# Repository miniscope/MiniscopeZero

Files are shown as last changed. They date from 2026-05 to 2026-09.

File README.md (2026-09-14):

# Miniscope Zero

Repository for **Miniscope Zero: a fully wireless, single-cell-resolution miniature microscope for imaging neural dynamics in freely behaving animals**.

Miniscope Zero is a miniature one-photon microscope that operates without tethers: power is delivered via quasistatic cavity resonance (QSCR) wireless power transfer, and imaging data is streamed over a high-bandwidth optical link. This repository hosts the project-specific hardware designs — the miniscope, the optical data acquisition hardware, and the QSCR arena — and points to the related software and hardware repositories.

- Preprint: [bioRxiv](https://doi.org/10.64898/2026.09.05.745822) (doi:10.64898/2026.09.05.745822)
- Wiki: https://miniscope.org/wiki/Miniscope_Zero
- License: [CERN-OHL-S v2](LICENSE) — bundled code retains its original license where noted: the vendored [Miniscope-SAMD-Framework](https://github.com/miniscope/Miniscope-SAMD-Framework) snapshot (`MS_module`) is AGPL-3.0, and Microchip ASF/Atmel START driver code keeps Microchip's license

Co-led by Takuya Sasatani ([@t-sasatani](https://github.com/t-sasatani)) and Marcel Brosch ([@MarcelMB](https://github.com/MarcelMB)).

## Demonstration video
https://github.com/user-attachments/assets/aa9ec822-df9f-4f50-9b2d-21a6ab23955f

## Repository contents

```
MiniscopeZero/                      Wireless miniscope
├── Firmware/                       SAMD51 firmware (Microchip Studio project)
├── Optics/                         Optical system
│   ├── optics_bom.csv              Bill of materials for the optical path
│   ├── mechanical/                 Dimensioned drawing of the optical assembly
│   ├── zemax/                      Zemax OpticStudio sequential design files
│   ├── housing/                    3D-printed housing: STEP, Fusion archive, per-body STLs
│   └── baseplate/                  CNC-machined baseplate, 3D-printed dust cap,
│                                   and set-screw hardware list
└── PCB/                            Electronics
    ├── WLMS-v0_2_1-motherboard/    Main board: PYTHON480 image sensor, MCU, PMU,
    │                               excitation LED, IR receiver
    ├── WLMS-v0_2_9_daughterboard/  Power/uplink board: rectifier, pre-regulator,
    │                               TX LED for the optical data link
    └── WPT_receiver/               Rectangular wireless power receiver coils

OpticalDAQ/                         Receiver-side data acquisition hardware
├── PCB/
│   ├── optical_daq_v0_4/           Photoreceiver front end: VGA board and digitizer board
│   ├── optical_downlink_v0_2/      USB board for the IR downlink
│   └── FPGA_breakout/              Breakout board for the Opal Kelly XEM7310 FPGA module
└── Housing/                        CNC aluminum shield box

QSCR/                               Quasistatic cavity resonance power-transfer arena
├── COMSOL/                         Electromagnetic simulation models of the arena
├── Fusion360/                      QSCR behavioral arena design files
└── PCB/c_mount/                    Capacitor mount PCB

guides/                             Build and operation guides
├── optics_assembly.md              Assembling the miniscope printed parts and optics
├── qscr_operation.md               QSCR cavity operation, tuning, and assembly
└── img/                            Figures for the guides
```

## Related repositories (developed by authors)

- [mio (Miniscope-I/O)](https://github.com/miniscope/mio) — data acquisition, synchronization, and preprocessing
- [CaMAP](https://github.com/miniscope/CaMAP) — calcium imaging mapping and analysis pipeline
- [miniscope_preproc](https://github.com/miniscope/miniscope_preproc) — preprocessing for Miniscope Zero calcium imaging videos
- [wpt-devkit](https://github.com/SasataniLab/wpt-devkit) — wireless power transmitter
- [FuzzyTrack](https://github.com/miniscope/FuzzyTrack) — diffused LED position tracking
- [Miniscope-SAMD-Framework](https://github.com/miniscope/Miniscope-SAMD-Framework) — firmware framework template; `Firmware/.../MS_module` is a minimal vendored snapshot of [v0.3.1](https://github.com/miniscope/Miniscope-SAMD-Framework/tree/v0.3.1)

## Hardware modules

Off-the-shelf or reference modules used in the system:

- [Hamamatsu C15522-3010SA](https://www.hamamatsu.com/us/en/product/optical-sensors/mppc/mppc-module/C15522-3010SA.html) — SiPM (MPPC) module, receiver for the optical data link
- [EPC9065](https://epc-co.com/epc/products/evaluation-boards/epc9065) — high-frequency ZVS class-D power amplifier, drives the QSCR cavity
- [Opal Kelly XEM7310](https://www.opalkelly.com/products/fpga-integration/XEM7310/) — Artix-7 FPGA board for data acquisition

## Batteries

- [Powerstream GM041215](https://www.powerstream.com/ultra-light.htm) — Low weight miniature lithium ion battery, 45mAH, 3.7V, 4x12x15 mm, 1 g
- [Powerstream GM300910](https://www.powerstream.com/ultra-light.htm) — Low weight miniature lithium ion battery, 11mAH, 3.7V, 3x9x10 mm, 0.33 g

## Contributing

This repository primarily archives the design files accompanying the paper, so
pull requests are unlikely to be merged. Questions and issue reports are
welcome via the issue tracker, though we cannot guarantee a response.

## Wireless system video
https://github.com/user-attachments/assets/bc67a5da-3641-4dcf-a8c2-b1db79f1c406

## Citing

If you use this work, please cite the [preprint](https://doi.org/10.64898/2026.09.05.745822) — BibTeX in [CITATION.bib](CITATION.bib), or use GitHub's "Cite this repository" button.

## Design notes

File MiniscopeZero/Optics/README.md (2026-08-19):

# Optics

Optical system of the Miniscope Zero head-mounted assembly: bill of materials,
mechanical drawing, optical design files, and housing/baseplate CAD.

## Contents

```
Optics/
├── optics_bom.csv    Bill of materials for the optical path
├── mechanical/       Dimensioned drawing of the optical assembly (Fusion 360 export)
├── zemax/            Ansys Zemax OpticStudio sequential-mode design files
├── housing/          3D-printed optical housing CAD
└── baseplate/        3D-printed baseplate CAD and hardware list
```

The housing holds the optical stack; the baseplate is cemented to the skull and
receives it. A set-screw mechanism sets the focal plane relative to the implanted
GRIN lens during baseplating, then locks it for subsequent recordings.

## Assembly

[`guides/optics_assembly.md`](../../guides/optics_assembly.md) is the build guide for the head-mounted assembly:
which optic goes into which printed part and in which orientation, edge
blackening and adhesive practice, the order the four printed parts are joined
in, and a dark-field leak test to run before the scope goes on an animal.

## Bill of materials

`optics_bom.csv` lists every element in the optical path. GitHub renders it as a
table in the web UI. The `ref` column keys each part to the mechanical drawing:

| ref | Element |
| --- | --- |
| `LED` | Excitation LED |
| `F_ex` | Excitation filter |
| `DM` | Dichroic beamsplitter |
| `L1`, `L2` | Objective (L2 is closest to the sample) |
| `L3` | Tube lens |
| `M1` | Fold mirror |
| `F_em` | Emission filter |
| `IS` | Image sensor |

Light path: `LED → F_ex → DM (transmitted) → L1 → L2 → sample`, then
`sample → L2 → L1 → DM (reflected 90°) → L3 → M1 (folded) → F_em → IS`.

Folding the path twice distributes the elements laterally rather than
vertically, keeping the assembly height low.

The `notes` column records where a part is **modified from stock** — the filters,
dichroic, and mirror are all diced down from larger catalog parts. Ordering the
stock part number alone will not give you a part that fits the housing.

Links in the `link` column point to the vendor part page, or to a vendor search
for the stock number where no stable product URL exists.

## Mechanical drawing

`mechanical/drawing_Miniscope_Wireless_emission_v_0_2_10.pdf` — dimensioned
layout of the optical stack, exported from Fusion 360 (design v0.2.10), with
element spacings in mm.

## Housing

`housing/` holds the 3D-printed optical housing (design v0.2.10):

- `Wireless_Miniscope_v_0_2_10.step` — all four bodies as exact solids. Use this
  to modify the design in any CAD package.
- `Wireless_Miniscope_v_0_2_10.f3d` — Fusion 360 archive with the design history.
- One STL per body, for printing:

| File | Body | Size (mm) |
| --- | --- | --- |
| `base_unit.stl` | Main chassis, tube-lens bore | 11.3 x 13.0 x 9.0 |
| `objective_unit.stl` | Objective lens holder | 7.9 x 2.1 x 7.9 |
| `excitation_unit.stl` | Excitation LED and filter arm | 7.6 x 7.6 x 9.0 |
| `focus_slider_unit.stl` | Set-screw focus slider | 8.4 x 10.0 x 8.0 |

The four parts print separately. Each STL is a single watertight, manifold shell
at the origin, so it can be oriented independently in the slicer.

Printed on a Formlabs Form 4 in Black Resin V5 at 25 um layer thickness.

## Baseplate and dust cap

`baseplate/` holds the skull-mounted baseplate and its dust cap. The two are
made differently:

| Part | Process | File to use |
| --- | --- | --- |
| Baseplate | CNC machined (Protolabs) | `baseplate.step` |
| Dust cap | 3D printed | `dust_cap.stl` |

The dust cap prints on the same settings as the housing: Formlabs Form 4, Black
Resin V5, 25 um layer thickness.

Baseplate machining specification (as ordered from Protolabs):

| | |
| --- | --- |
| Material | Aluminium 7075-T651 |
| Process | Mill |
| Dimensions | 14.59 x 5.99 x 14.89 mm |
| Tolerance | +/- 0.005 in (0.13 mm) |
| Edges | Broken; tool marks visible |
| Internal corners | Sharp, at minimum tool radius |
| Threading | 1 feature, UNF #2-64 |

The threaded bore is highlighted in green below. It takes the set screw that
locks the optical stack in the baseplate once the focal plane is set.

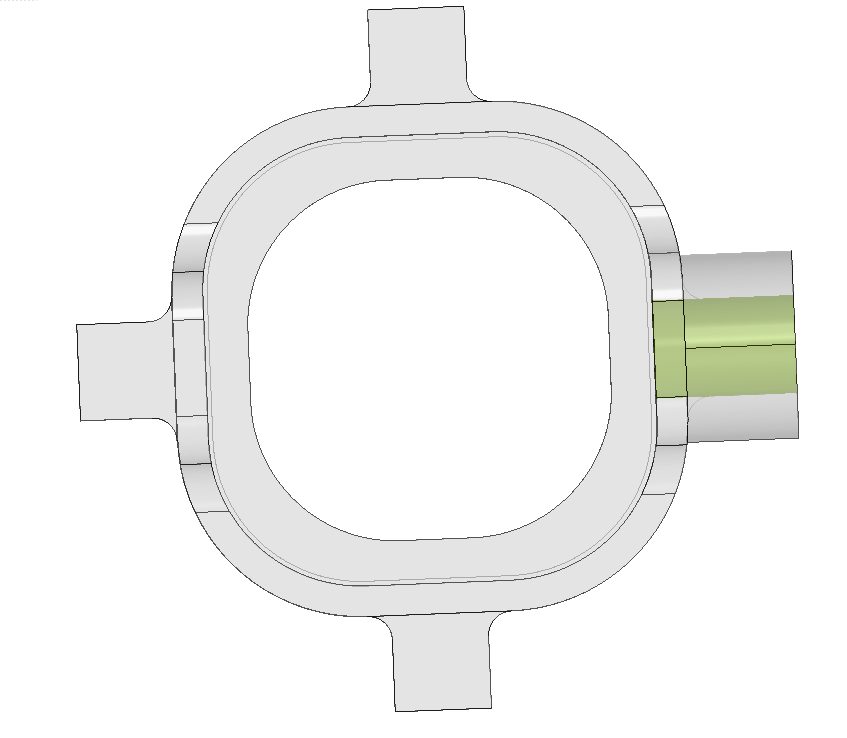
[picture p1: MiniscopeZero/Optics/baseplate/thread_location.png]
Baseplate seen from above, with the UNF #2-64 threaded bore highlighted in green


`baseplate.step` is the exact solid sent for machining; `baseplate.stl` is the
tessellated equivalent, for viewing and fit checks. `baseplate_and_dustcap.f3z`
is the Fusion 360 assembly archive for both parts.

`baseplate/baseplate_components.csv` lists the hardware that goes with it: the
McMaster-Carr `92311A317` set screw (18-8 stainless, cup tip, 2-64 UNF x 1/8 in,
0.035 in / 0.9 mm hex drive) and the precision hex driver used to turn it.

## Optical design

`zemax/` contains the sequential-mode OpticStudio models:

- `Miniscope_Wireless_emission_v_0_2_6_mirror_as_prism_2ndaspheric_14572.zmx`
  — emission path (the fold mirror is modelled as a prism).
- `Miniscope_Wireless_excitation_v_0_2_2.zmx` — excitation path.
- `emission_prescription_data.txt` — prescription dump of the emission model
  (surface data, NA, working F/#, track length), readable without OpticStudio.

`.ZDA` files are the matching OpticStudio session/analysis files.

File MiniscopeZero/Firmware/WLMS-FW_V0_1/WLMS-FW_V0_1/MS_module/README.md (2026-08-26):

# Miniscope-SAMD-Framework

Firmware framework for wireless miniature microscopes (miniscopes) based on Microchip SAM D51 microcontrollers. The framework reads out a CMOS image sensor (ON Semiconductor PYTHON 480 or AMS NanEye) through the parallel capture controller (PCC), buffers image data in MCU RAM, and streams it via DMA to a serial data link (SPI/USART) or an SD card. It also controls miniscope peripherals such as the electrowetting lens (EWL), excitation LED, battery and wireless-power voltage monitoring, an IR receiver for remote control, and status LEDs.

The framework is designed to be used as a git submodule inside a Microchip Studio (Atmel START) project. Pre-build scripts link the framework sources into the generated project so that Atmel START files are never edited directly.

## Repository structure

- `src/`: application sources
- `include/`: headers, including the build configuration (`MS_config.h`)
- `ASF_custom/`: customized Atmel Software Framework (ASF) drivers, stored with `.csrc`/`.hsrc` extensions and installed by the pre-build script
- `script/`: PowerShell scripts that install/uninstall the framework sources into the parent Atmel START project
- `atstart/`: Atmel START configuration archives (`.atzip`) for supported hardware
- `main.csrc`: application entry point, installed as the parent project's `main.c`
- `Doxyfile`, `html/`: Doxygen documentation; open `html/index.html` in a browser after cloning

## Requirements

- Microchip Studio with an Atmel START project targeting a SAM D51 device
- PowerShell (invoked by the pre-build event)

## Setup

1. Create an Atmel START project configured with the drivers and pins listed under [Peripheral requirements](#peripheral-requirements-atmel-start-config). The archives in `atstart/` can be used as a starting point.
2. From the directory containing the project's `main.c`, add this repository as a submodule:
   ```bash
   git submodule add https://github.com/Aharoni-Lab/Miniscope-SAMD-Framework ./MS_module
   ```
3. In the Microchip Studio Solution Explorer, click "Show All Files", right-click `MS_module`, and select "Include in Project".
4. Add the following to the include paths (Project -> Properties -> Toolchain -> ARM/GNU C Compiler -> Directories, configuration: All configurations):
   ```
   ../MS_module/include
   ```
5. Add the following pre-build event (configuration: All configurations):
   ```
   powershell.exe -ExecutionPolicy Bypass -NoProfile -NonInteractive -File "..\MS_module\script\MS_prebuild.ps1"
   ```

The pre-build script replaces the generated `main.c` and selected ASF drivers with the versions in this repository (`main.csrc`, `ASF_custom/`) using hard links. Before re-running Atmel START code generation, run `script/MS_pre_reconfig.ps1` to restore the original files.

Do not modify Atmel START generated driver files directly. To customize an ASF driver, add the modified file to `ASF_custom/` (with a `.csrc`/`.hsrc` extension) and register its path in `$cfilepatharray`/`$headerpatharray` in `MS_prebuild.ps1` and `MS_pre_reconfig.ps1`.

## Configuration

All build configuration is done with compile-time flags in `include/MS_config.h`.

### Mode flags

Select exactly one hardware mode (`*_MODE` or `*_TESTMODE`), which determines the data path and the set of peripherals compiled in:

```c
// ------ HARDWARE MODE ------------------------
//#define V4WF_MODE
#define WLMS_SPI_MODE
//#define BERT_MODE
//#define GS_MODE
//#define WLMS_USART_MODE
//#define WLMS_SD_MODE
//#define DMA_TO_SPI_TESTMODE
//#define DMA_TO_SPI_METRO_TESTMODE
```

For example, `WLMS_SPI_MODE` streams PYTHON 480 image data over SPI, `WLMS_SD_MODE` records to an SD card, and `BERT_MODE` streams a PRBS test pattern for bit-error-rate testing of the data link.

### Peripheral flags

Each mode defines the peripherals to enable (`*_ENABLE` / `*_DISABLE`) together with mode-specific parameters (buffer sizes, frame rate, sensor ROI, device ID, etc.):

```c
#ifdef WLMS_SPI_MODE
#define PYTHON480_ENABLE
#define EWL_ENABLE
#define DMA_TO_SPI_ENABLE
#define EXLED_PWM_ENABLE
#define BATTERY_ENABLE
// ...
#endif
```

### Conditional compilation

Peripheral code should be guarded by the peripheral's `_ENABLE` flag (not by mode flags):

```c
#ifdef PYTHON480_ENABLE
gpio_set_pin_level(EN_3V3, true); // Enable the 3.3V regulator
I2C_BB_init();
#endif
```

### SERCOM for data output

The SERCOM used for serial data output is configured in Atmel START. On the firmware side, select the corresponding `SPI_SERCOMx_ENABLE` or `USART_SERCOMx_ENABLE` flag in the mode definition; the DMA destination register is resolved from this flag (see `src/MS_global_variable.c`).

## Peripheral requirements (Atmel START config)

### PYTHON480_ENABLE

Drivers:

```
TIMER_0
CAMERA_0
EXTERNAL_IRQ_0
```

Pins:

```
SPI_BB_SCK
SPI_BB_MOSI
SPI_BB_MISO
SPI_BB_NSS
PCC_D0,...,PCC_D7
PCC_CLK
PCC_HV
PCC_FV
FrameValid
EN_3V3
RESET_CMOS
MONITOR0
GCLK1_OUT
```

### BATTERY_ENABLE

```
BATT_VOLT
```

### WPT_ADC_ENABLE

```
WPT_VOLT
```

### EWL_ENABLE

```
I2C_BB_SCL
I2C_BB_SDA
```

### IR_TRIGGER_ENABLE / IR_UART_ENABLE

```
IR_RX
```

### EXLED_PWM_ENABLE

```
LED_PWM
ENT_LED
```

## Documentation

API documentation is generated with Doxygen and committed under `html/`; open `html/index.html` in a browser. To regenerate, run `doxygen Doxyfile` in the repository root.

## License

This project is licensed under the GNU Affero General Public License v3.0; see [LICENSE](LICENSE). The modified ASF driver files in `ASF_custom/` are derived from the Atmel Software Framework and retain their original Microchip/Atmel license headers.

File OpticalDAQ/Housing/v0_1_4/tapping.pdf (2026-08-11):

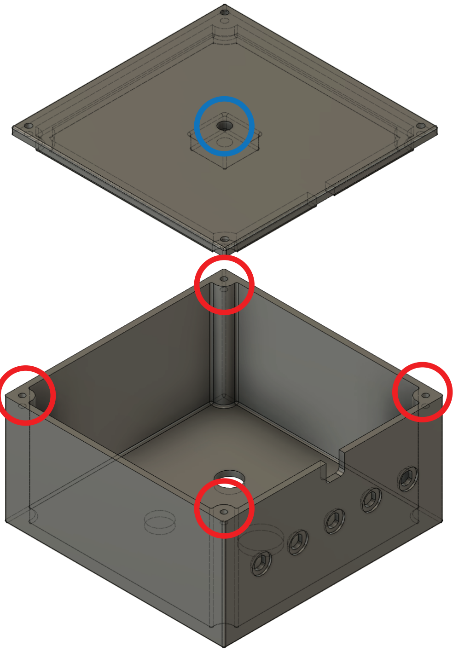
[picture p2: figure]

Red circled holes: M, mm depth thread

Blue circled hole:
UNC/- (JIS B compliant) with a depth of mm

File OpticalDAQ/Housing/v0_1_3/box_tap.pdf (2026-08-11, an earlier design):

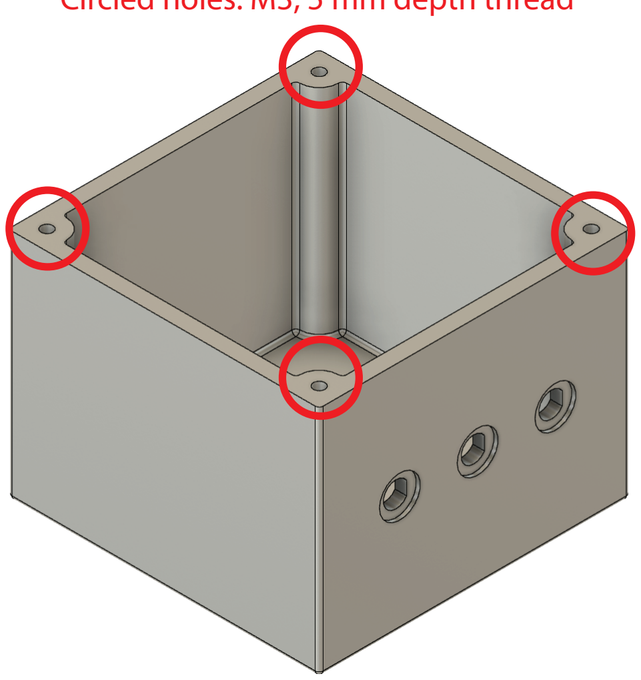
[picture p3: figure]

Circled holes: M3, 5 mm depth thread

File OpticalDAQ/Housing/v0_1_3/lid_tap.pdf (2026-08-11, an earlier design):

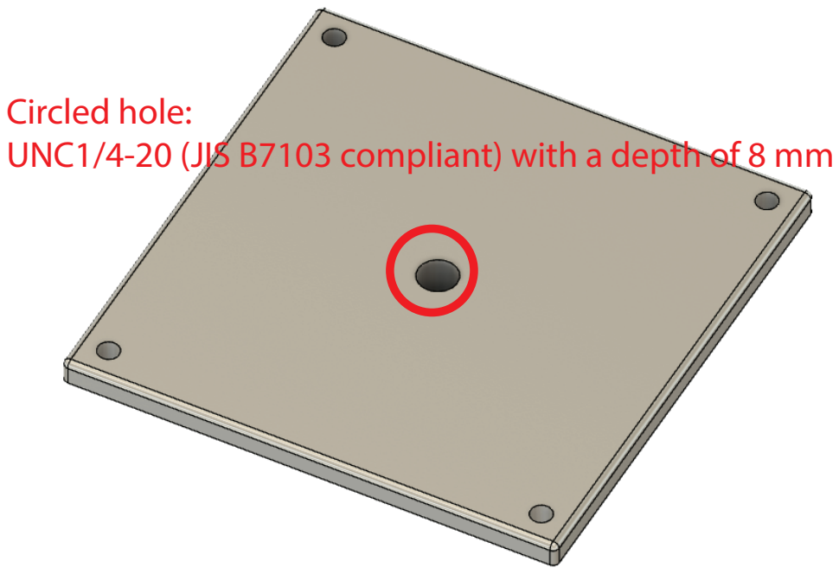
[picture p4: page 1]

Circled hole:
UNC1/4-20 (JIS B7103 compliant) with a depth of 8 mm

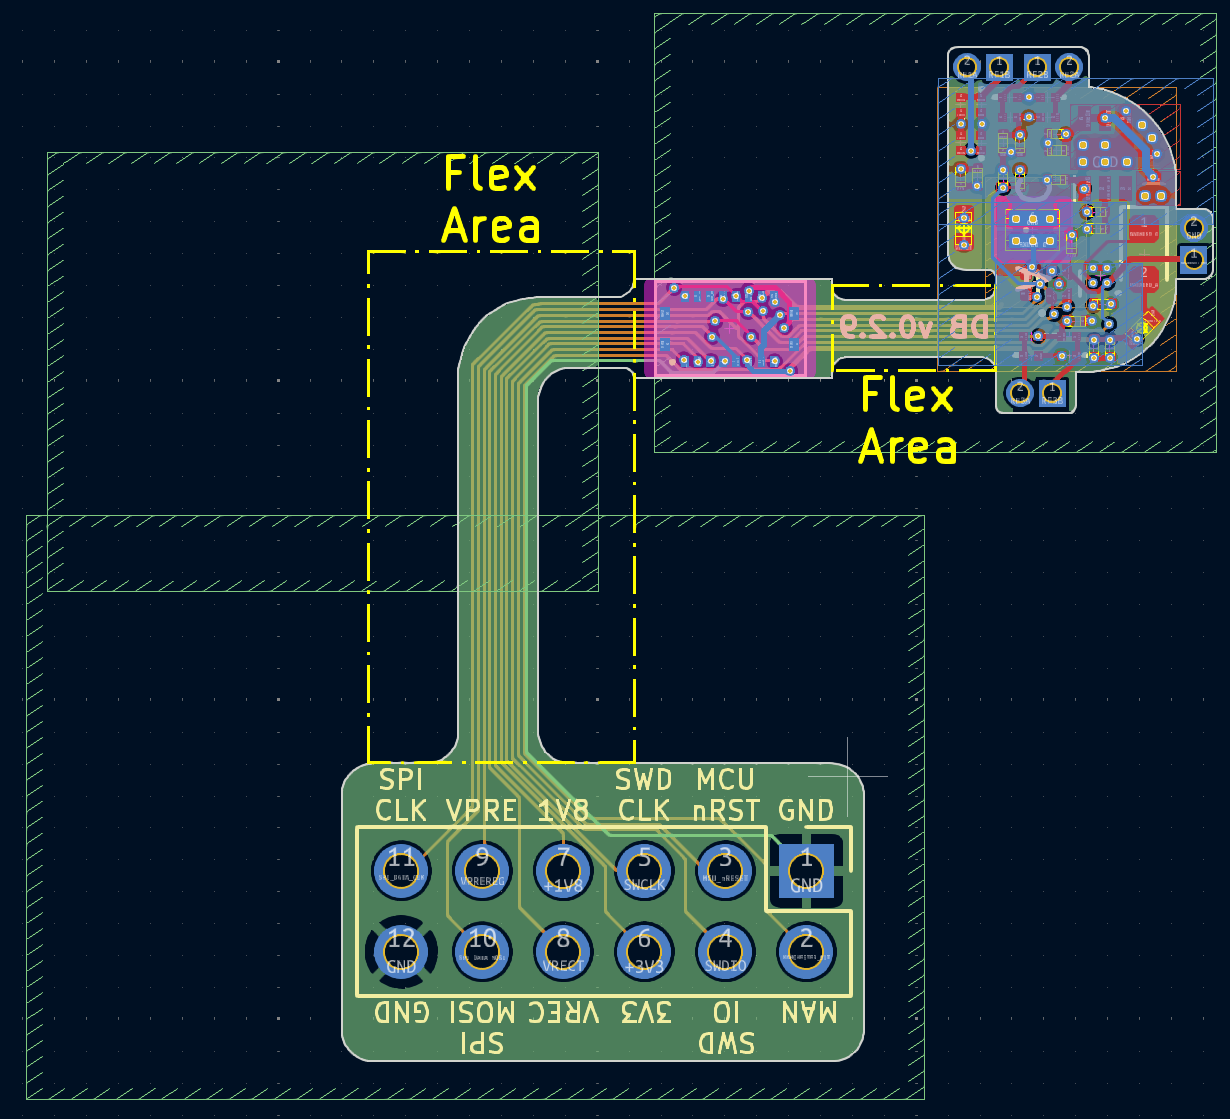
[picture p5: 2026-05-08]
MiniscopeZero/PCB/WLMS-v0_2_9_daughterboard/Assembly/rigid-flex-overview.png

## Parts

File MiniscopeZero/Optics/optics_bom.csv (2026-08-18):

ref | category | component | vendor | part_number | qty | specs | notes | link
LED | excitation | Excitation LED | Lumileds | LXZ1-PB01 | 1 | LUXEON Z blue; 470 nm dominant (460-480 nm); 1.3 x 1.7 mm emitter; ~3 V |  | https://lumileds.com/products/color-leds/luxeon-z-colors/
F_ex | excitation | Excitation filter | Chroma | ET470/40x | 1 | Bandpass 450-490 nm | Diced to 2 x 2 x 0.5 mm | https://www.chroma.com/products/parts/et470-40x
DM | shared | Dichroic beamsplitter | Chroma | T500spxr | 1 | Shortpass, ~500 nm edge; transmits 470 nm excitation, reflects 525 nm emission | Diced to 5 x 7 x 1 mm | https://www.chroma.com/products/parts/t500spxr
L1 | objective | Molded asphere | Edmund Optics | 15-273 | 1 | Polycarbonate; 8.0 mm dia; EFL 5.9 mm; uncoated | Objective, dichroic side | https://www.edmundoptics.com/search/?criteria=15-273
L2 | objective | Plano-convex lens | Edmund Optics | 45-226 | 1 | N-BAF10; 4.0 mm dia; EFL 8.0 mm; MgF2 AR 400-700 nm | Objective, closest to sample | https://www.edmundoptics.com/search/?criteria=45-226
L3 | emission | Molded asphere (tube lens) | Edmund Optics | 14-572 | 1 | Polycarbonate; 8.0 mm dia; EFL 6.9 mm; uncoated |  | https://www.edmundoptics.com/search/?criteria=14-572
M1 | emission | Fold mirror | Thorlabs | PFR10-P01 | 1 | UV fused silica; 25 x 36 x 1 mm stock; protected silver (P01); Ravg > 97% 450 nm - 2 um | Diced to 5 x 7 x 1 mm | https://www.thorlabs.com/thorproduct.cfm?partnumber=PFR10-P01
F_em | emission | Emission filter | Chroma | ET525/50m | 1 | Bandpass 500-550 nm | Diced to 5 x 5 x 1 mm | https://www.chroma.com/products/parts/et525-50m
IS | emission | Image sensor | onsemi | NOIP1SN0480A-STI | 1 | PYTHON 480 monochrome CMOS; 808 x 608 px; 4.8 um pixel; global shutter |  | https://www.onsemi.com/products/sensors/image-sensors/noip1sn0480a

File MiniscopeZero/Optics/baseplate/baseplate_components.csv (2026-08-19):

item | part_number | manufacturer | supplier | qty_per_baseplate | description | drive_type | drive_size | thread_size | thread_type | thread_fit | thread_direction | major_diameter | length | head_type | tip_type | material | hardness | performance | standards | pack_size | price_usd | price_basis | link | notes
set_screw | 92311A317 | McMaster-Carr | McMaster-Carr | 1 | 18-8 stainless steel cup-tip set screw that locks the miniscope body into the implanted baseplate | Hex | 0.035 in (0.89 mm) | 2-64 | UNF (fine) | Unified Standard Class 3A | Right hand | 0.086 in (2.18 mm) | 1/8 in (3.18 mm) | Headless | Cup | 18-8 stainless steel | Rockwell B80 | Corrosion resistant | ASME B18.3 | 10 | 4.09 | per pack of 10 | https://www.mcmaster.com/92311A317/ | Cup tip digs into the surface for a secure hold.
driver | 263P 0.9 (Wiha art. 00520; US catalog 26343) | Wiha | Wiha / DigiKey / any precision tool supplier | 1 | PicoFinish precision hex screwdriver, 0.9 mm (0.035 in), for tightening the baseplate set screw | Hex | 0.035 in (0.9 mm) |  |  |  |  |  | 40 mm blade, 134 mm overall |  |  | Chrome-vanadium-molybdenum steel, through hardened, chrome-plated |  | ChromTop exact-fit tip; rotating cap for fingertip control |  | 1 | 6.42 | each (DigiKey, 26343); approx EUR 8.43 retail in EU | https://www.digikey.com/en/products/detail/wiha/26343/1987746 | Tool in use in the lab. Nothing special about this exact model - any precision driver that fits the 0.035 in / 0.9 mm hex socket of 92311A317 works. Avoid Torx or star tips that merely engage the hex; a mismatched tip will round out the socket on a screw that is repeatedly loosened and retightened.

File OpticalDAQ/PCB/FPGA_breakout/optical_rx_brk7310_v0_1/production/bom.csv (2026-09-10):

Designator | Footprint | Quantity | Value | LCSC Part #
J1, J2 | SAMTEC_BTE-040-01-F-D-A | 2 | BTE-040-01-F-D-A
J10, J11, J12, J13, J9 | PinHeader_1x02_P2.54mm_Vertical | 5 | Conn_01x02_Pin
J3, J4, J5, J6, J7 | SMA_Amphenol_901-144_Vertical | 5 | Conn_Coaxial
J8 | PinHeader_1x06_P2.54mm_Vertical | 1 | Conn_01x06_Pin

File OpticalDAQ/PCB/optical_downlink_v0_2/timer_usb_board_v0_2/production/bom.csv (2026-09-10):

Designator | Footprint | Quantity | Value | LCSC Part #
C1, C3, C4, C7, C9 | 0603 | 5 | 0.1u
C2 | CP_EIA-1608-08_AVX-J | 1 | 10u
C5 | 0603 | 1 | 10u
C6 | CP_Elec_4x5.4 | 1 | 10u
C8 | 0603 | 1 | C_osc
D1 | 0603 | 1 | LED_GREEN
D2 | 0603 | 1 | LED_RED
D3, D4, D5 | D_SOD-923 | 3 | ESD9B5.0ST5G
F1 | 1206 | 1 | Polyfuse
IC1 | SOT65P210X110-5N | 1 | SN74LV1T86DCKRG4
J1 | USB_Micro-B_Amphenol_10118194-0001LF_Horizontal | 1 | USB_B_Micro
J4, J5, J7 | SMA_Amphenol_901-143_Horizontal | 3 | Conn_Coaxial
J6 | PinHeader_1x03_P2.54mm_Vertical | 1 | Conn_01x03_Pin
R1, R2 | 0603 | 2 | 470
R3 | 0603 | 1 | 2k
R4 | 0603 | 1 | 4.7k
R5 | 0603 | 1 | 1k
R6 | 0603 | 1 | R_osc
TP1, TP2 | TestPoint_Pad_D2.0mm | 2 | TestPoint
U1 | SSOP-28_5.3x10.2mm_P0.65mm | 1 | FT232RL
U2 | SOIC-8_3.9x4.9mm_P1.27mm | 1 | LMC555xM

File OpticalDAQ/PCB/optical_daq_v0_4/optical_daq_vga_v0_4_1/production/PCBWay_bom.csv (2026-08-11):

Designator | Quantity | Value | Footprint | Package | MPN | DNP | Mount_Type | Description
C1, C10, C16, C17, C3, C5, C9 | 7 | 1000p | C_0603_1608Metric |  | GRM1885C1H102JA01D |  | smt | Unpolarized capacitor
C11, C14, C18, C7 | 4 | 10u | C_1206_3216Metric |  | GRM31CR71E106KA12L |  | smt | Unpolarized capacitor
C12 | 1 | 0.47u | C_0603_1608Metric |  | GRM188R71E474KA12D |  | smt | Unpolarized capacitor
C13, C6 | 2 | 10u/tant | CP_EIA-3216-10_Kemet-I |  | TAJA106K010RNJ |  | smt | Polarized capacitor
C15, C19, C8 | 3 | 4.7u | C_0603_1608Metric |  | GRM188Z71A475ME15D |  | smt | Unpolarized capacitor
C2, C4 | 2 | 0.1u | C_0603_1608Metric |  | GCJ188R71E104KA12D |  | smt | Unpolarized capacitor
D1, D2 | 2 | LED | LED_0603_1608Metric |  | 150060RS75003 |  | smt | Light emitting diode
FB1, FB2 | 2 | FerriteBead | L_0603_1608Metric |  | BLM18KG121TN1D |  | smt | Ferrite bead
J1 | 1 | DNP | PinHeader_1x02_P2.54mm_Vertical |  |  | Yes | tht | Generic connector, single row, 01x02, script generated
J10, J11, J4, J9 | 4 | Conn_Coaxial | SMA_Amphenol_901-144_Vertical |  | RF2-04A-T-00-50-G |  | tht | coaxial connector (BNC, SMA, SMB, SMC, Cinch/RCA, LEMO, ...)
J12 | 1 | DNP | PinHeader_1x02_P2.54mm_Vertical |  |  | Yes | tht | Generic connector, single row, 01x02, script generated
J13 | 1 | DNP | PinHeader_1x02_P2.54mm_Vertical |  |  | Yes | tht | Generic connector, single row, 01x02, script generated
J14 | 1 | DNP | PinHeader_1x02_P2.54mm_Vertical |  |  | Yes | tht | Generic connector, single row, 01x02, script generated
J15 | 1 | DNP | SMA_Amphenol_901-144_Vertical |  |  | Yes | tht | coaxial connector (BNC, SMA, SMB, SMC, Cinch/RCA, LEMO, ...)
J16 | 1 | Screw_Terminal_01x04 | TerminalBlock_TE_282834-4_1x04_P2.54mm_Horizontal |  | 282834-4 | Yes | tht | Generic screw terminal, single row, 01x04, script generated (kicad-library-utils/schlib/autogen/connector/)
J17 | 1 | DNP | SMA_Amphenol_901-144_Vertical |  |  | Yes | tht | coaxial connector (BNC, SMA, SMB, SMC, Cinch/RCA, LEMO, ...)
J18 | 1 | DNP | SMA_Amphenol_901-144_Vertical |  |  | Yes | tht | coaxial connector (BNC, SMA, SMB, SMC, Cinch/RCA, LEMO, ...)
J19 | 1 | DNP | SMA_Amphenol_901-144_Vertical |  |  | Yes | tht | coaxial connector (BNC, SMA, SMB, SMC, Cinch/RCA, LEMO, ...)
J2 | 1 | DNP | SMA_Amphenol_901-144_Vertical |  |  | Yes | tht | coaxial connector (BNC, SMA, SMB, SMC, Cinch/RCA, LEMO, ...)
J20 | 1 | DNP | PinHeader_1x02_P2.54mm_Vertical |  |  | Yes | tht | Generic connector, single row, 01x02, script generated
J21 | 1 | DNP | PinHeader_1x02_P2.54mm_Vertical |  |  | Yes | tht | Generic connector, single row, 01x02, script generated
J3 | 1 | DNP | SMA_Amphenol_901-144_Vertical |  |  | Yes | tht | coaxial connector (BNC, SMA, SMB, SMC, Cinch/RCA, LEMO, ...)
J5 | 1 | DNP | PinHeader_1x02_P2.54mm_Vertical |  |  | Yes | tht | Generic connector, single row, 01x02, script generated
J6 | 1 | DNP | PinHeader_1x02_P2.54mm_Vertical |  |  | Yes | tht | Generic connector, single row, 01x02, script generated
J7 | 1 | DNP | PinHeader_1x02_P2.54mm_Vertical |  |  | Yes | tht | Generic connector, single row, 01x02, script generated
J8 | 1 | DNP | PinHeader_1x02_P2.54mm_Vertical |  |  | Yes | tht | Generic connector, single row, 01x02, script generated
R1 | 1 | 121k | R_0603_1608Metric |  | ERJ-3EKF1213V |  | smt | Resistor
R10 | 1 | DNP | R_0603_1608Metric |  |  | Yes | smt | Resistor
R11, R12, R13, R7 | 4 | 0 | R_0603_1608Metric |  | CRCW06030000Z0EA |  | smt | Resistor
R14 | 1 | DNP | R_0603_1608Metric |  |  | Yes | smt | Resistor
R15, R9 | 2 | 1k | R_0603_1608Metric |  | CRCW06031K00FKEA |  | smt | Resistor
R16 | 1 | DNP | R_0603_1608Metric |  |  | Yes | smt | Resistor
R17, R18 | 2 | 49.9 | R_0603_1608Metric |  | ERJ-3EKF49R9V |  | smt | Resistor
R2, R3 | 2 | 154k | R_0603_1608Metric |  | ERJ-3EKF1543V |  | smt | Resistor
R20, R27 | 2 | 10k | R_0603_1608Metric |  | CR0603-FX-1002ELF |  | smt | Resistor
R21, R28 | 2 | 470m | R_0603_1608Metric |  | ERJ-3RQJR47V |  | smt | Resistor
R22, R29 | 2 | 453k | R_0603_1608Metric |  | ERJ-3EKF4533V |  | smt | Resistor
R23 | 1 | 300 | R_0603_1608Metric |  | ERJ-PA3F3000V |  | smt | Resistor
R24, R31 | 2 | 33.2k | R_0603_1608Metric |  | ERJ-3EKF3322V |  | smt | Resistor
R25, R32 | 2 | 49.9k | R_0603_1608Metric |  | CRCW060349K9FKEA |  | smt | Resistor
R30 | 1 | 7.5k | R_0603_1608Metric |  | ERJ-3EKF7501V |  | smt | Resistor
R4 | 1 | DNP | R_0603_1608Metric |  |  | Yes | smt | Resistor
R5 | 1 | 30.1k | R_0603_1608Metric |  | ERJ-3RBD3012V |  | smt | Resistor
R6 | 1 | DNP | R_0603_1608Metric |  |  | Yes | smt | Resistor
R8 | 1 | DNP | R_0603_1608Metric |  |  | Yes | smt | Resistor
RV1, RV2 | 2 | 3314G-1-104E | Potentiometer_Bourns_3314G_Vertical |  | 3314G-2-104E |  | smt | Potentiometer
TP3 | 1 | DNP | TestPoint_Keystone_5000-5004_Miniature |  |  | Yes | tht | test point
TP4 | 1 | DNP | TestPoint_Keystone_5000-5004_Miniature |  |  | Yes | tht | test point
TP5 | 1 | DNP | TestPoint_Keystone_5000-5004_Miniature |  |  | Yes | tht | test point
TP6 | 1 | DNP | TestPoint_Keystone_5000-5004_Miniature |  |  | Yes | tht | test point
TP7 | 1 | DNP | TestPoint_Keystone_5000-5004_Miniature |  |  | Yes | tht | test point
U1 | 1 | AD8264 | HVQFN-40-1EP_6x6mm_P0.5mm_EP4.1x4.1mm |  | AD8264ACPZ |  | smt | Quad, 235 MHz, 6-30 dB gain, ±2.5 V to ±5 V supply, DC-Coupled VGA and Differential Output Amplifier, QFN-40
U2 | 1 | LT3045xDD | DFN-10-1EP_3x3mm_P0.5mm_EP1.65x2.38mm |  | LT3045EDD#PBF |  | smt | 500mA, Adjustable, Ultralow Noise, Ultrahigh PSRR Linear Regulator, DFN-10
U3 | 1 | LT3094xDD | DFN-12-1EP_3x3mm_P0.45mm_EP1.65x2.38mm_ThermalVias |  | LT3094EDD#TRPBF |  | smt | –20V, 500mA, Ultralow Noise, Ultrahigh PSRR Negative Linear Regulator, -1.8..-20Vin, 0..-19.5Vout, DFN-12

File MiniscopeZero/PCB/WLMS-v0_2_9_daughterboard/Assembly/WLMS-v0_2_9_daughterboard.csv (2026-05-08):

Id | Designator | Footprint | Quantity | Designation | Supplier and ref
1 | FB1 | L_0201_0603Metric | 1 | FerriteBead (0 Ohm)
2 | D5,D8,D11,D13,D9,D6,D15,D12,D10,D3,D4,D14 | PMEG3002EEFZ | 12 | PMEG3002EEFZ
3 | R1 | R_0201_0603Metric_ERJ_L | 1 | 9.1k
4 | J6,J3,J5,J4 | PinHeader_1x02_P1.00mm_Vertical | 4 | Conn_01x02_Pin
5 | R2 | R_0201_0603Metric_ERJ_L | 1 | 1k
6 | C12,C9,C7,C1 | C_0201_0603Metric_L | 4 | 1000p
7 | R4 | R_0201_0603Metric_ERJ_L | 1 | 30k
8 | C5 | C_0402_1005Metric_L | 1 | 10u
9 | C6,C3,C10,C8,C2,C13,C11 | C_0201_0603Metric_L | 7 | 0.1u
10 | IC2 | Texas_X2SON-5_0.8x0.8mm_P0.48mm | 1 | 74LV1T86GXH
11 | IC1 | LDFMPVR | 1 | LDFMPVR
12 | R5 | R_0402_1005Metric_ERJ_L | 1 | R
13 | D7 | BZX884B7V5LHG308 | 1 | BZX884B7V5
14 | D1 | LED_0603_1608Metric | 1 | LED
15 | C4 | C_0201_0603Metric_L | 1 | 1u
16 | J7 | PinHeader_2x06_P2.54mm_Vertical | 1 | Conn_02x06_Odd_Even
17 | Q1 | EPC2038 | 1 | EPC2038
18 | R3 | R_0201_0603Metric_ERJ_L | 1 | 150k
19 | D2 | LED_LXZ1_PR01_L | 1 | LXZ1-PB01
20 | J1 | 5055511620 | 1 | 505551-1620

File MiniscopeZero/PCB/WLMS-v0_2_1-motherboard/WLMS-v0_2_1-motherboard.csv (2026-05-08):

Id | Designator | Footprint | Quantity | Designation | Supplier and ref
1 | C9,C8 | C_0201_0603Metric_L | 2 | 22pF
2 | R8,R18 | R_0201_0603Metric_ERJ_L | 2 | R_Small_US
3 | C13,C25,C19,C15,C14,C24,C12,C29,C10,C11,C23,C32,C33,C30,C27,C28,C26,C21,C22,C31 | C_0201_0603Metric_L | 20 | 0.1uF
4 | R6 | R_0201_0603Metric_ERJ_L | 1 | 1.25M
5 | D1,D2 | LED_SC80X160X65L40L | 2 | LED_Small_ALT
6 | L1,L6,L5 | L_0603_1608Metric_L | 3 | BLM18PG471SN1D
7 | C16,C34 | C_0201_0603Metric_L | 2 | 4.7uF
8 | TP1,TP2 | Conn_1x1_800x1200_Pad | 2 | TestPoint
9 | R7 | R_0201_0603Metric_ERJ_L | 1 | 2.05M
10 | Q2 | TRXSOFL3P40_120X120X55L29X21L | 1 | NTK3134NT1G
11 | R10 | R_0201_0603Metric_ERJ_L | 1 | 649K
12 | R9 | R_0201_0603Metric_ERJ_L | 1 | 1M
13 | Y1 | Crystal_SMD_MicroCrystal_CC8V-T1A-2Pin_2.0x1.2mm | 1 | Crystal
14 | C38,C5 | C_0201_0603Metric_L | 2 | 2.2uF
15 | Q1 | TRXDFN3_101X61X53L25X15N | 1 | MMBT3904LP-7B
16 | C18,C35,C7,C6,C2,C17,C37,C1,C36 | C_0402_1005Metric_L | 9 | 10uF
17 | L2,L4 | C_0805_2012Metric_L | 2 | 10uH
18 | J1 | 5055501620 | 1 | 5055501620
19 | L3 | C_0805_2012Metric_L | 1 | 4.7uH
20 | R12 | R_0201_0603Metric_ERJ_L | 1 | 10K
21 | R15 | R_0201_0603Metric_ERJ_L | 1 | 47k5
22 | U4 | UQFN_MCP1711 | 1 | NCP163AMX330TBG
23 | C4,C3 | C_0201_0603Metric_L | 2 | 10pF
24 | U5 | SON_4_P300_395X395X90L55X35L | 1 | TSOP57438TT1
25 | SW1 | SMD-Switch-3mmx2mm | 1 | TL3780AF330QG
26 | R16 | R_0201_0603Metric_ERJ_L | 1 | 37K
27 | R17,R13 | R_0201_0603Metric_ERJ_L | 2 | 1K
28 | C39,C20 | C_0201_0603Metric_L | 2 | 1uF
29 | R3,R2 | R_0201_0603Metric_ERJ_L | 2 | 25K
30 | IC2 | BGA6C40P2X3_81X121X68 | 1 | LP5522TM_NOPB
31 | R19 | R_0201_0603Metric_ERJ_L | 1 | 2K
32 | R20 | R_0201_0603Metric_ERJ_L | 1 | 8.2K
33 | R4 | R_0201_0603Metric_ERJ_L | 1 | 400K
34 | U1 | QFN-20-1EP_3x3mm_P0.4mm_EP1.65x1.65mm | 1 | LTC3554
35 | IC1 | SON50P100X150X55-6N | 1 | LMV881LE_NOPB
36 | R11,R1,R5 | R_0201_0603Metric_ERJ_L | 3 | 100K
37 | R14 | R_0201_0603Metric_ERJ_L | 1 | DNL
38 | U3 | BGA88CP50_8X11_493X613X75B25 | 1 | NOIP1SN0480A
39 | U2 | ATSAMD51J20A-UUT-EFP | 1 | ATSAMD51J20A-UUT-EFP

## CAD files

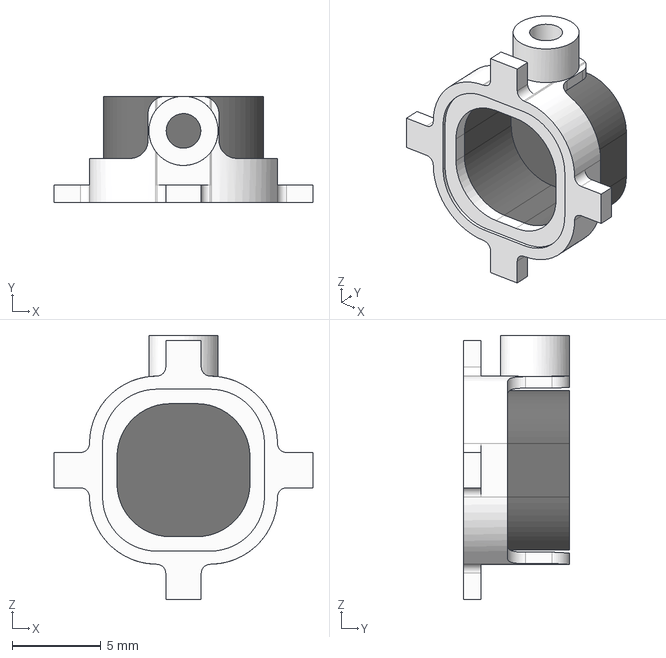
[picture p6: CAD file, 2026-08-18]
MiniscopeZero/Optics/baseplate/baseplate.step
14.6 x 6.00 x 14.9 mm

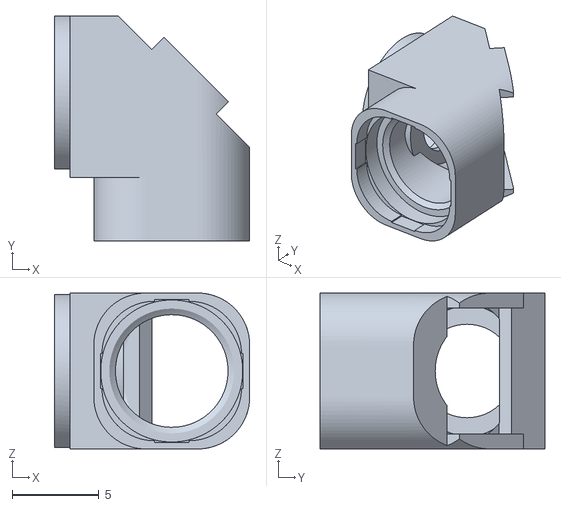
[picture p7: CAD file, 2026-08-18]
MiniscopeZero/Optics/housing/base_unit.stl
11.3 x 13.0 x 9.00

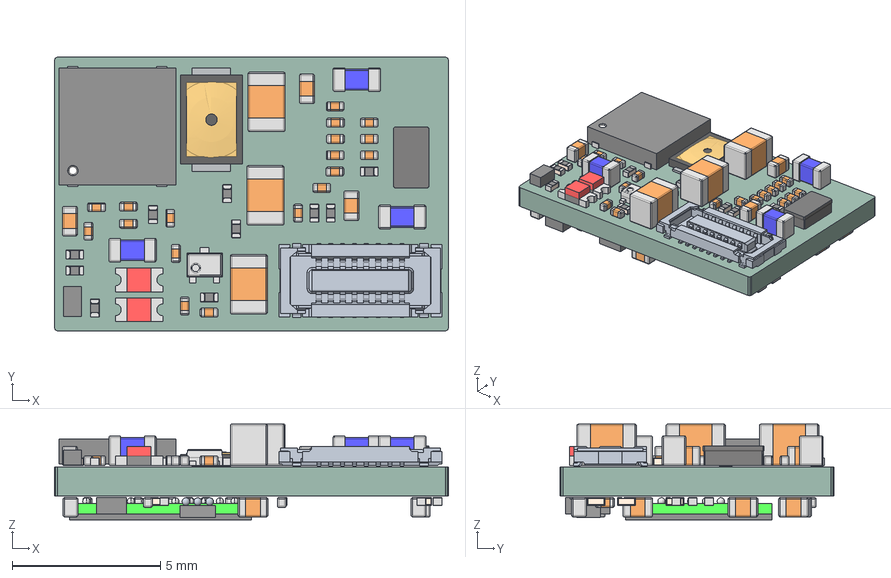
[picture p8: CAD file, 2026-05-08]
MiniscopeZero/PCB/WLMS-v0_2_1-motherboard/WLMS-v0_2_1-motherboard.step
13.3 x 9.23 x 3.23 mm
WLMS-v0_2-motherboard PCB

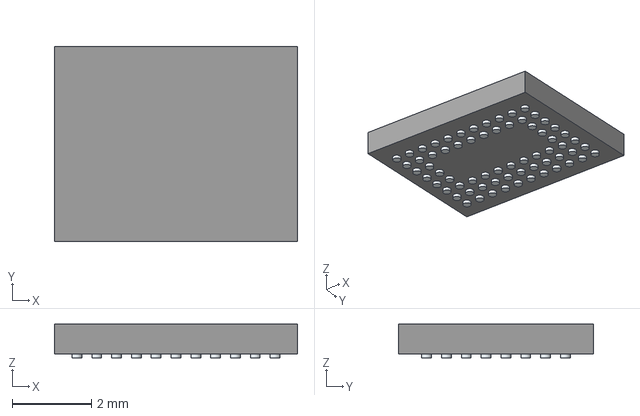
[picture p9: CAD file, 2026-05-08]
MiniscopeZero/PCB/WLMS-v0_2_9_daughterboard/3D Models/NOIP1SP0480A-STI.stp
6.13 x 4.93 x 0.85 mm
Pins

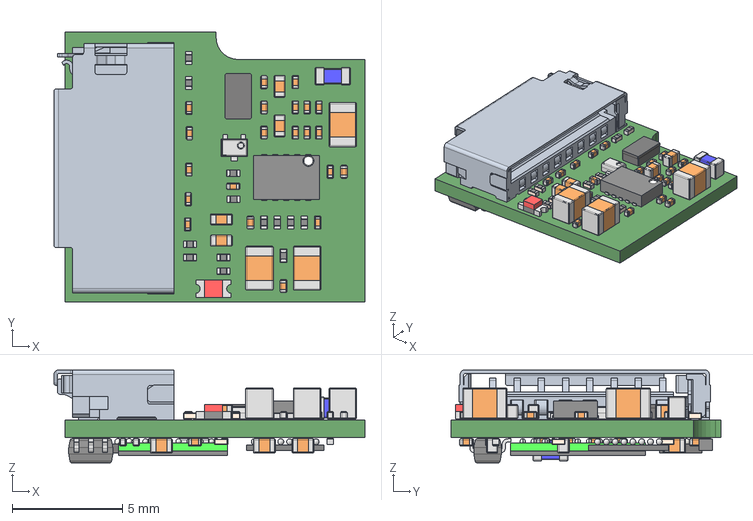
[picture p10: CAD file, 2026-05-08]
MiniscopeZero/PCB/WLMS-v0_2_9_daughterboard/WLMS-v0_2_9_daughterboard.step
14.1 x 12.2 x 4.22 mm

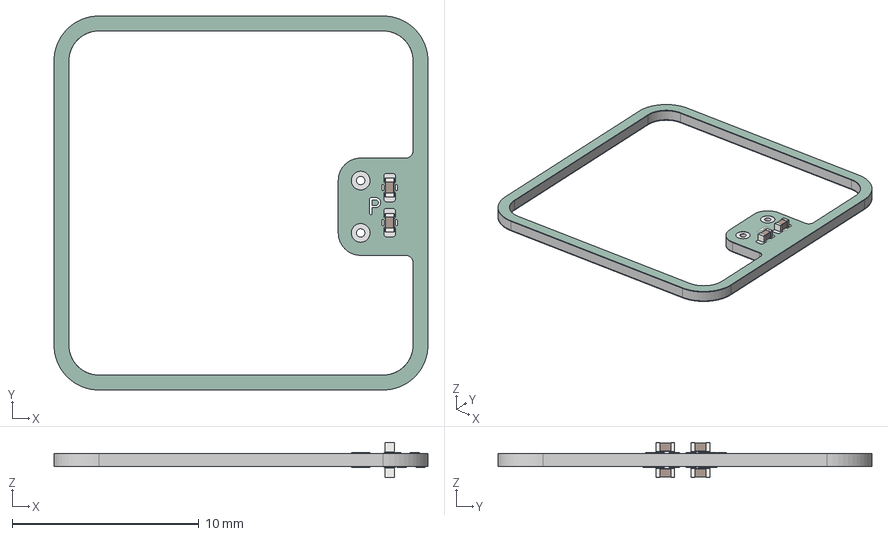
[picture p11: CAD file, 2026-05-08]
MiniscopeZero/PCB/WPT_receiver/rect_20_20/rect_20_20.step
20.0 x 20.0 x 1.88 mm
C_0402_1005Metric x 4
rect_20_20_pad
rect_20_20_silkscreen
rect_20_20_soldermask
rect_20_20_PCB

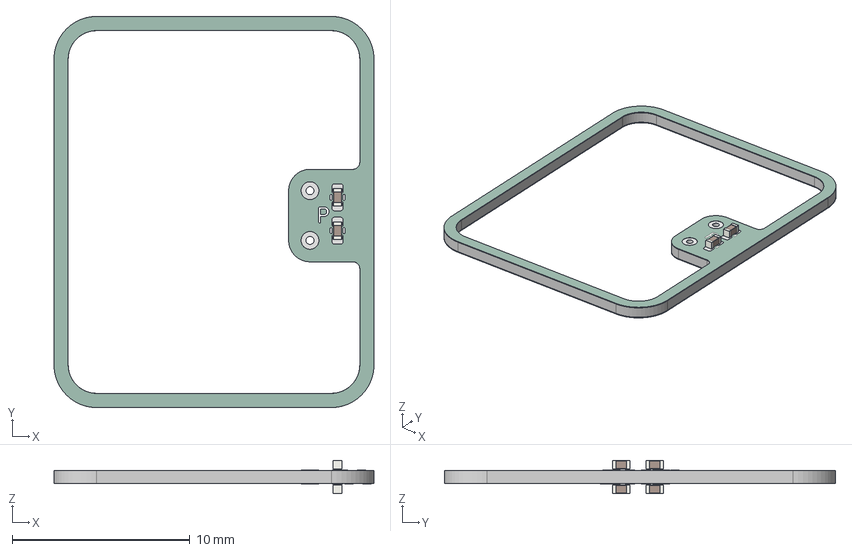
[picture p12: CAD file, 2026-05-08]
MiniscopeZero/PCB/WPT_receiver/rect_22_18/rect_22_18.step
18.0 x 22.0 x 1.88 mm
C_0402_1005Metric x 4
rect_22_18_pad
rect_22_18_silkscreen
rect_22_18_soldermask
rect_22_18_PCB

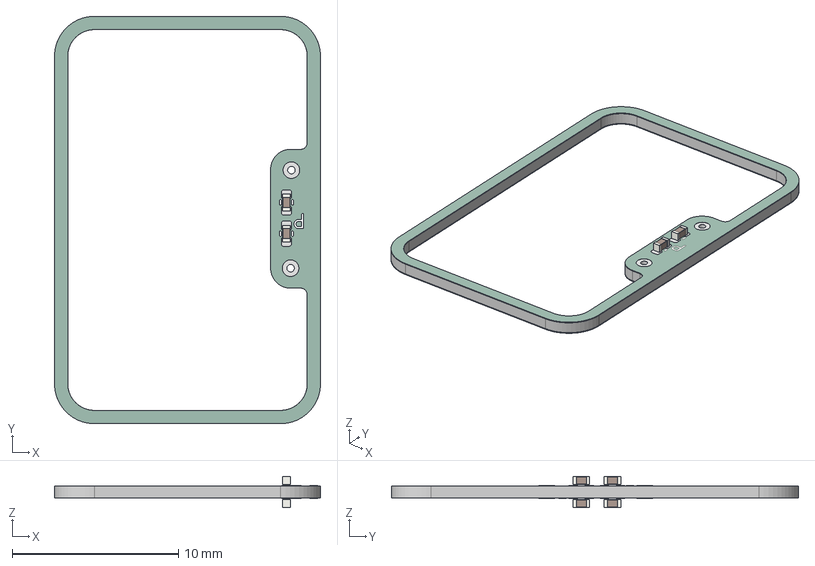
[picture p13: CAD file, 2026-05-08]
MiniscopeZero/PCB/WPT_receiver/rect_24-5_16/rect_24-5_16.step
16.0 x 24.5 x 1.88 mm
C_0402_1005Metric x 4
rect_24-5_16_pad
rect_24-5_16_silkscreen
rect_24-5_16_soldermask
rect_24-5_16_PCB

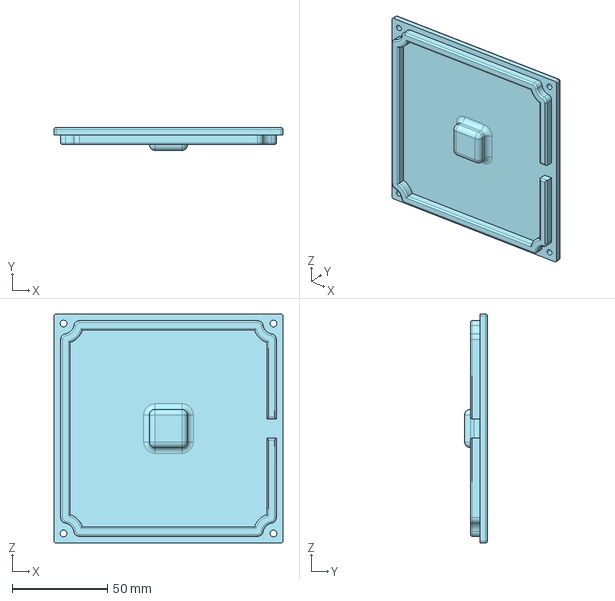
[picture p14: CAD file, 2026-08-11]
OpticalDAQ/Housing/v0_1_4/lid.step
120.0 x 12.0 x 120.0 mm

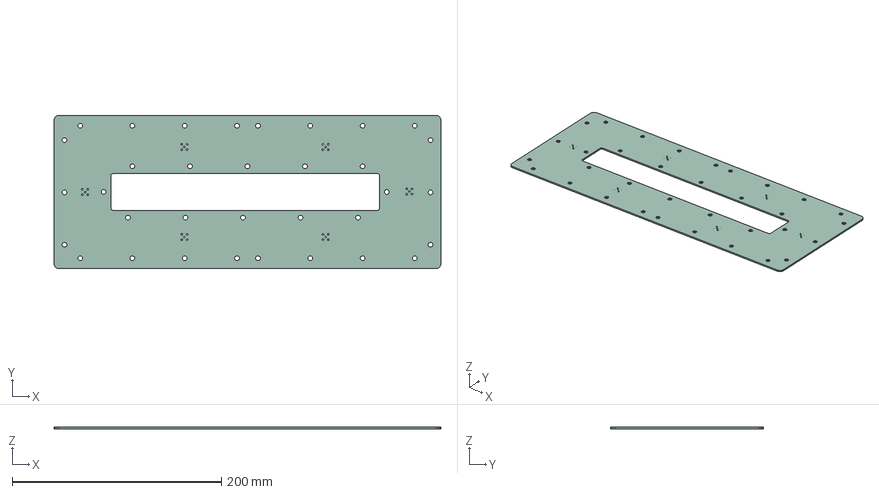
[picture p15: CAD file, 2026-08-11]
QSCR/PCB/c_mount/c_mount.step
370.0 x 146.6 x 1.58 mm

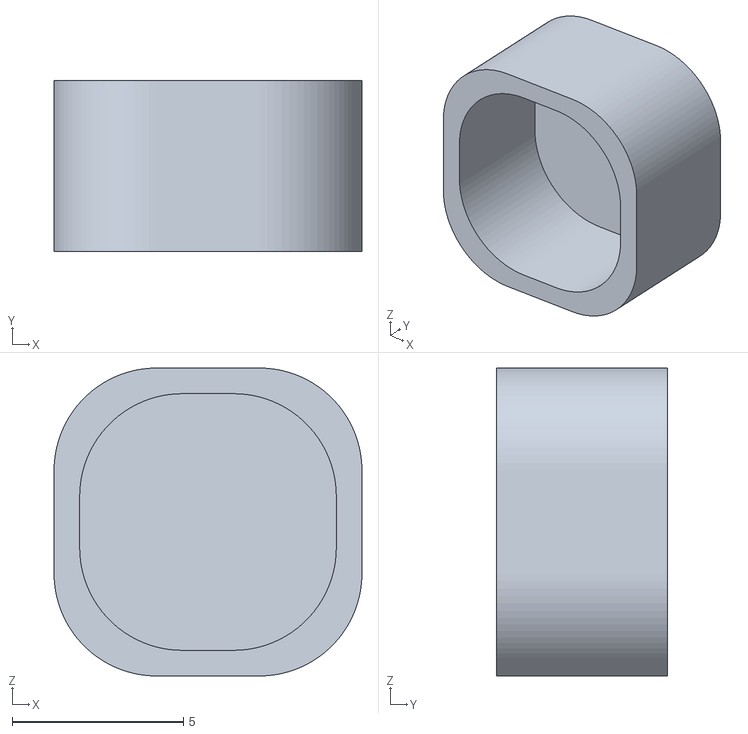
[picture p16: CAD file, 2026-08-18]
MiniscopeZero/Optics/baseplate/dust_cap.stl
9.00 x 5.00 x 9.00

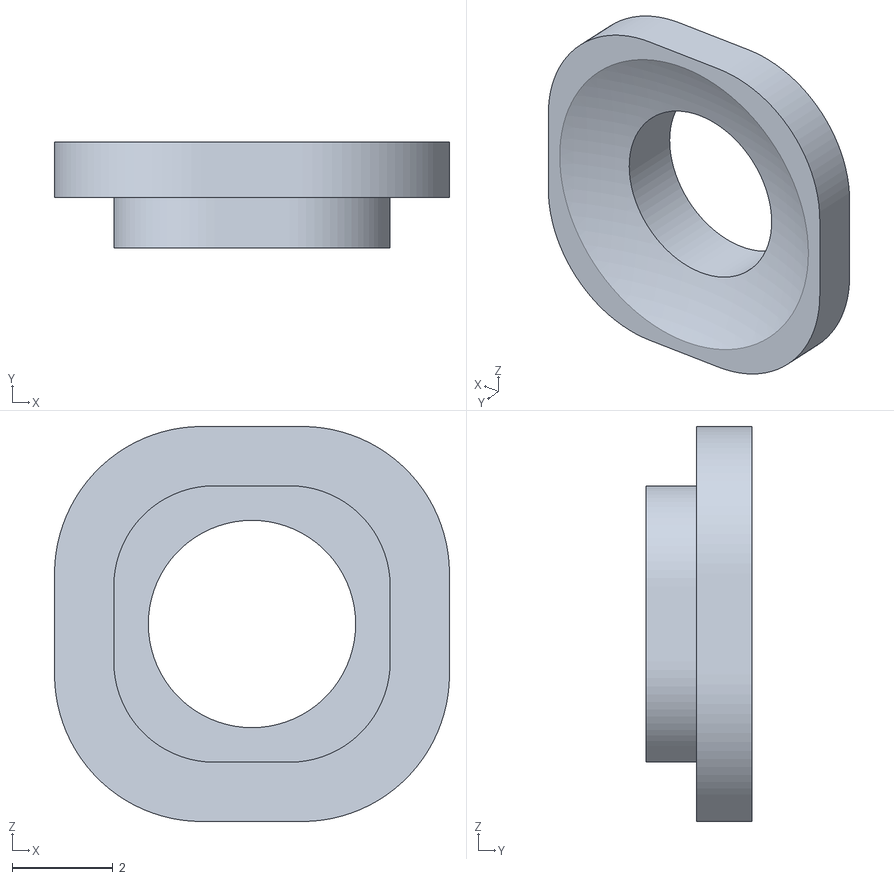
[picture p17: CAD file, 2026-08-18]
MiniscopeZero/Optics/housing/objective_unit.stl
7.86 x 2.11 x 7.86

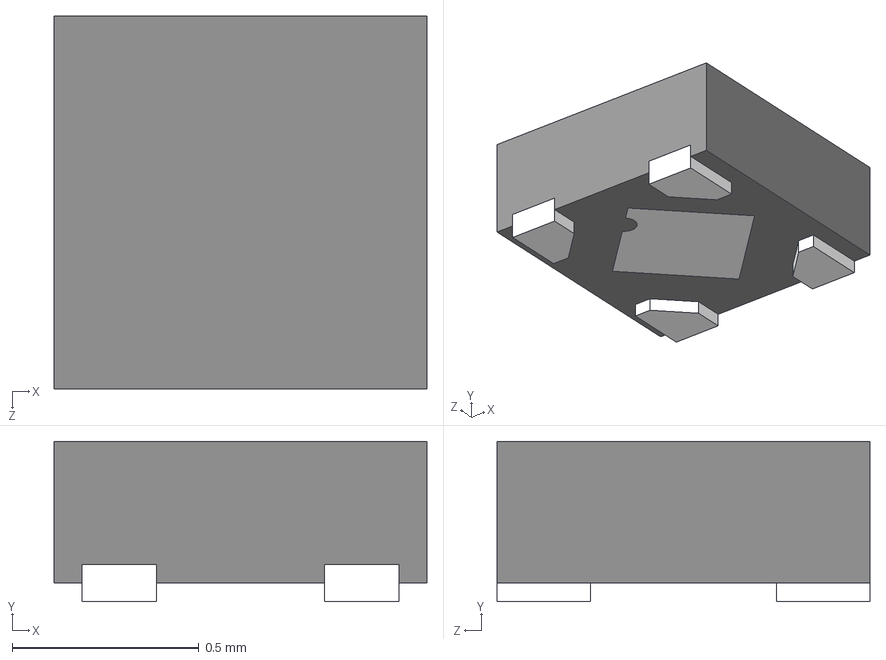
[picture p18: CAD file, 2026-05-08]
MiniscopeZero/PCB/WLMS-v0_2_1-motherboard/3D Models/NCP163AMX180TBG.stp
1.00 x 0.43 x 1.00 mm

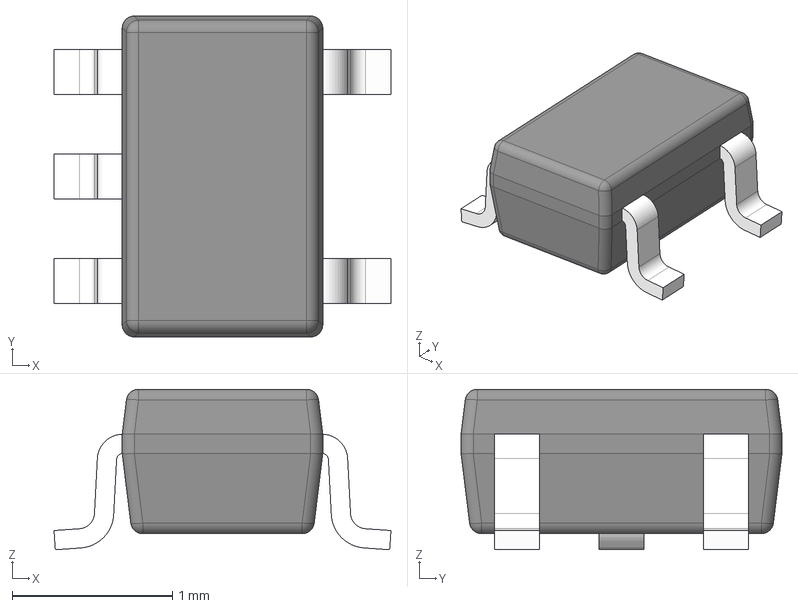
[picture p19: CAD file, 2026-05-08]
MiniscopeZero/PCB/WLMS-v0_2_9_daughterboard/3D Models/LMV321IDCKR.stp
2.10 x 2.00 x 1.00 mm
BODY-SOT
LEAD-SOT x 5
PIN1-ID

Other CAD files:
OpticalDAQ/Housing/v0_1_4/Inlet.step
MiniscopeZero/Optics/housing/Wireless_Miniscope_v_0_2_10.step
MiniscopeZero/PCB/WLMS-v0_2_9_daughterboard/3D Models/HV892K7-G.stp
MiniscopeZero/Optics/baseplate/baseplate.stl
MiniscopeZero/Optics/baseplate/baseplate_and_dustcap.f3z
MiniscopeZero/Optics/housing/Wireless_Miniscope_v_0_2_10.f3d
MiniscopeZero/Optics/housing/excitation_unit.stl
MiniscopeZero/Optics/housing/focus_slider_unit.stl
MiniscopeZero/PCB/WLMS-v0_2_1-motherboard/3D Models/475710001.stp
MiniscopeZero/PCB/WLMS-v0_2_1-motherboard/3D Models/5055501620.stp
MiniscopeZero/PCB/WLMS-v0_2_1-motherboard/3D Models/ERJ-1GNF4023C.stp
MiniscopeZero/PCB/WLMS-v0_2_1-motherboard/3D Models/FH19C-4S-0.5SH.stp
MiniscopeZero/PCB/WLMS-v0_2_1-motherboard/3D Models/GRM033R61A105ME15D.stp
MiniscopeZero/PCB/WLMS-v0_2_1-motherboard/3D Models/GRM035R60J475ME15D.stp
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

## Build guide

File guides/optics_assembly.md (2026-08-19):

# Miniscope Zero — assembling the printed parts and optics

Version `v_0_2_10`. This guide covers the mechanical and optical assembly of the
scope body: the four printed parts, the two aspheres, the plano-convex lens, the
mirror, and the three filters. It assumes the PCBs (excitation LED board and
image sensor board) are already populated and tested.

Everything is small, most of it is snap-fit, and almost every failure mode is
either a scratched coating or a light leak. Work slowly and dry-fit before any
glue touches a part. **Wear gloves** — skin oils on a lens or filter surface are
hard to remove and scatter light exactly where you can least afford it.

---

## 1. The four printed parts

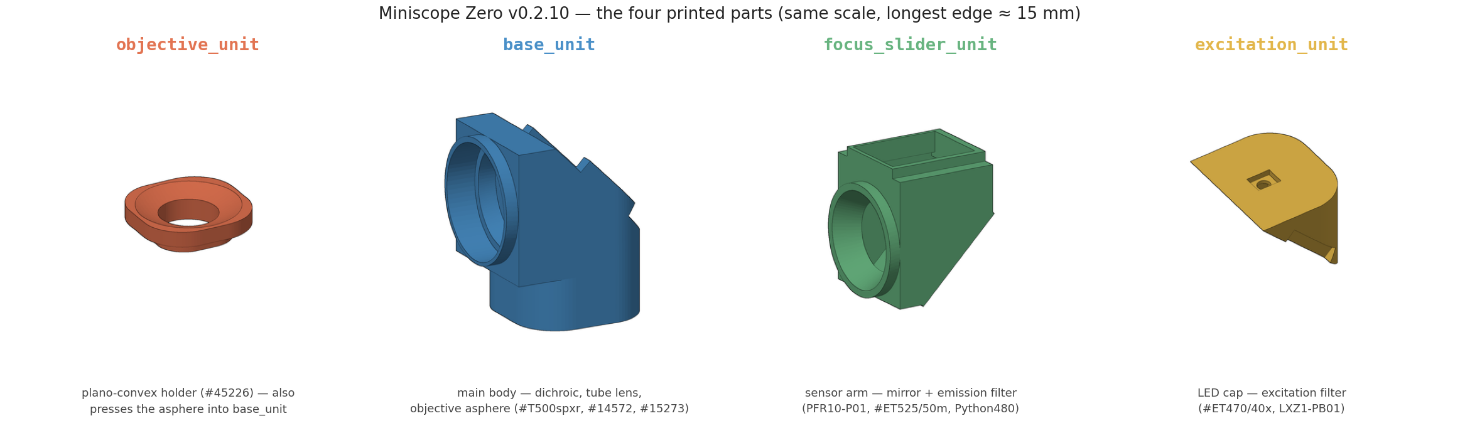
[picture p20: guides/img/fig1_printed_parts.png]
The four printed parts


| Part | Holds |
|---|---|
| `objective_unit` | plano-convex #45226 |
| `base_unit` | dichroic #T500spxr, tube lens asphere #14572, objective asphere #15273 |
| `focus_slider_unit` | mirror PFR10-P01, emission filter #ET525/50m, image sensor #Python480 |
| `excitation_unit` | excitation filter #ET470/40x, excitation LED LXZ1-PB01 |

Assembled, they sit like this:

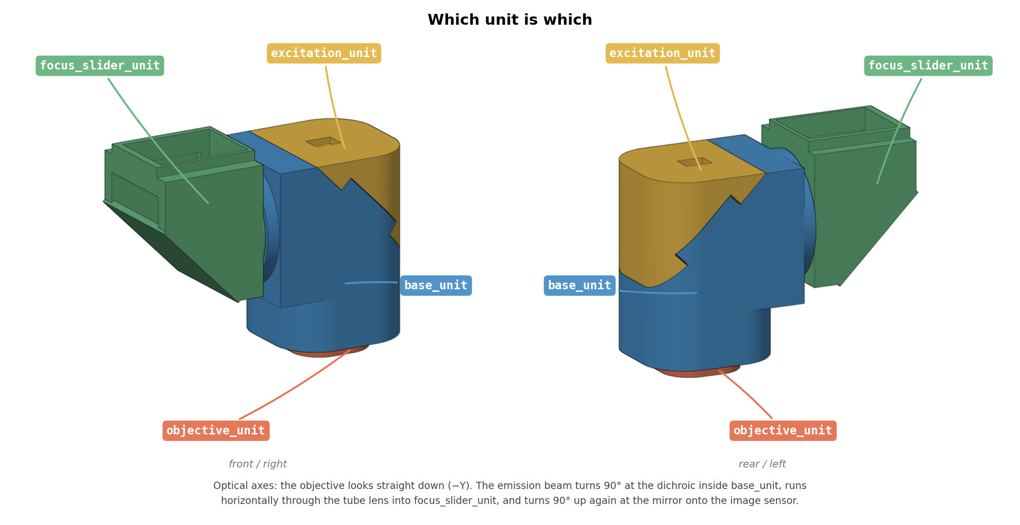
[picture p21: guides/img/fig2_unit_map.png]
Which unit is which


> **Note on `focus_slider_unit`:** this is a legacy name carried over from an
> earlier prototype. **It does not adjust focus.** Working distance is set by the
> height of the implanted baseplate. The name is kept only so that CAD files,
> STLs and older documentation stay cross-referenceable.

---

## 2. Consumables and materials

| Item | What we use | Notes |
|---|---|---|
| Optical adhesive | Norland Optical Adhesive 68 | UV-cure and reworkable. Always tiny droplets. |
| Black paint | Mousou Black (Koyo Orient Japan Co.) | For sealing seams and edges. |
| Black marker | Any black permanent marker (Sharpie) | Convenient for optic edges, but see below — often not black enough. |
| Fine brush | Any fine artist's brush | For applying black paint into small pockets and around edges. |
| UV source | Any 365–405 nm curing lamp | |

**Glue rule:** two tiny droplets in two places is always better than one large
droplet in one place. Excess adhesive wicks across clear apertures and fouls PCB
components. Norland 68 is reworkable — cured joints can be taken apart again,
which is precisely why we use it — but relying on that is still much more work
than dosing correctly the first time.

**Paint rule:** let black paint dry fully before handling or before the next
step. Build coverage from **several thin layers rather than one thick one** — a
thick layer stays soft underneath, creeps into places it should not be, and can
lift later.

---

## 3. Rules that apply to every optic

Read this section once before touching anything — it applies to all filters,
both aspheres, the plano-convex lens, and the mirror.

**Blacken the edges.** Coat the side faces (the ground edges, never the clear
apertures) of every filter, lens and the mirror before installation. Uncoated
edges scatter light around the optic and directly reduce contrast on the sensor.

A permanent marker is quick and fine for this, but **a Sharpie is often not
actually black enough** — it still transmits a surprising amount at these path
lengths. Where it matters, use **Mousou Black applied with a fine brush**
instead. Thin layers, fully dried.

**Identify the coated side.** Every filter has one coated surface and one that
looks more translucent. Coating orientation matters optically and is called out
per optic below. The coated surface is also the fragile one — **avoid scratches
on the coated side above all else.** Handle by the edges only.

**Aspheres are directional and not interchangeable.** The two aspheres
(#14572 and #15273) are **different lenses**, and each has a "belly" (convex
side) that must face a specific direction. Check the optical drawing every time:

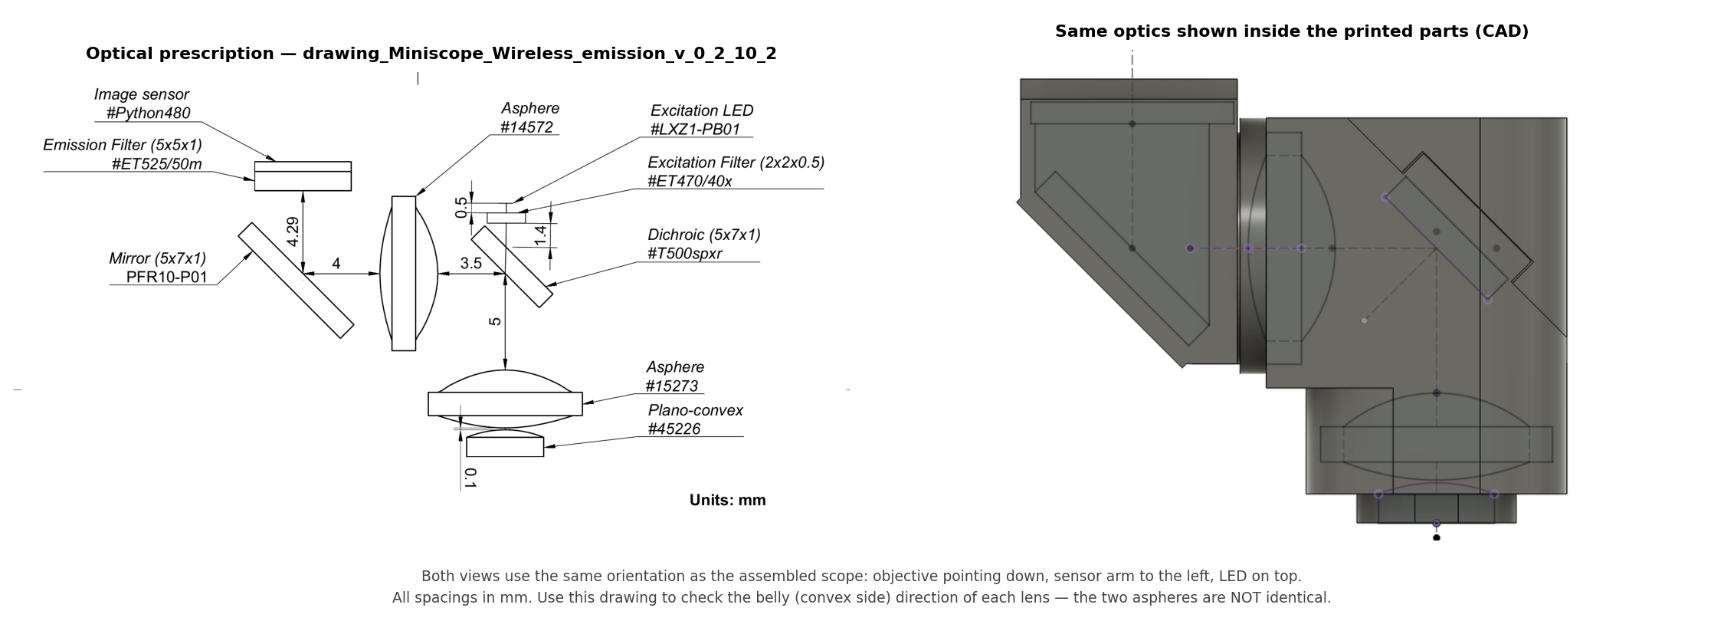
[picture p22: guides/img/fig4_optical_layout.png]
Optical layout


**Nothing except the joints in section 5 needs glue.** All lenses and all
printed-to-printed interfaces are snap fits. If a part does not click in, the
answer is print scaling or post-curing — not force.

---

## 4. Populating each unit

Optics go into each printed part **before** the parts are joined together.

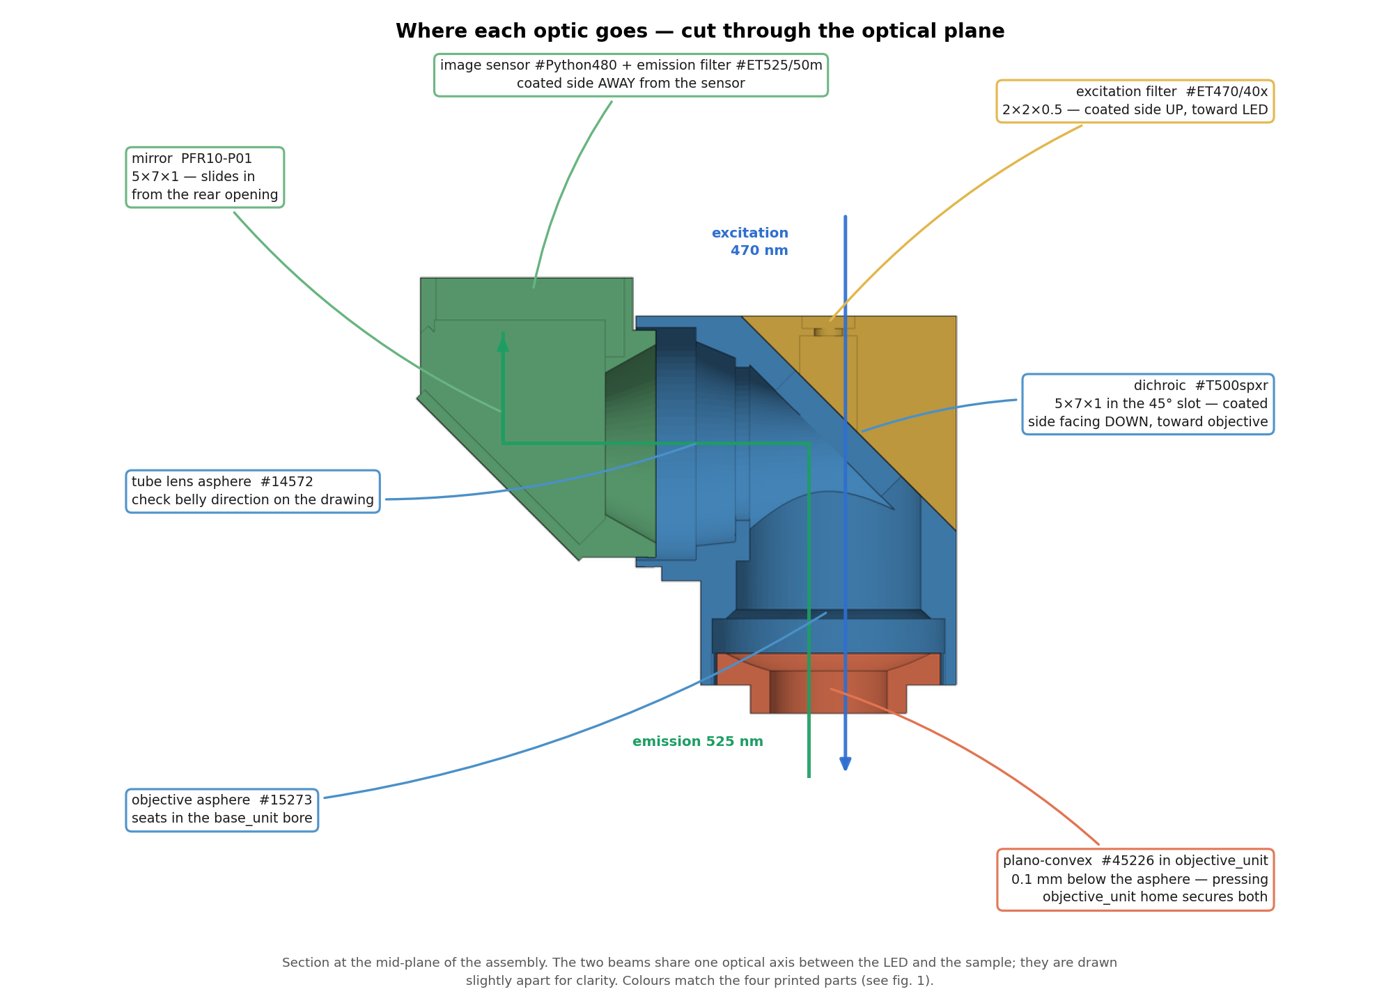
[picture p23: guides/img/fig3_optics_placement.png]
Where each optic goes


### 4.1 `excitation_unit` — excitation filter and LED

1. Drop the excitation filter **#ET470/40x (2 × 2 × 0.5)** into the pocket on the
   top face, **coated side up, toward the LED**. It must sit **flat** in the
   pocket — a tilted filter will not seal and will vignette the illumination.
2. If the fit is loose, one drop of UV glue will hold it.
3. Blacken the filter edges, **especially on the lower side** — the top opening
   where the LED sits is tight enough that light does not get in that way. A fine
   brush works well for applying the black paint here. This is the single most
   important light-leak control in the whole build: any excitation light that gets
   past the filter edge enters the emission path directly and shows up as a raised
   background floor on the sensor.
4. Glue the excitation LED PCB onto the top of the unit. Position the **LXZ1-PB01
   die carefully inside the opening** so it is neither tilted nor laterally
   offset — this is what determines illumination uniformity across the FOV later.

### 4.2 `base_unit` — dichroic and tube lens

1. Snap the tube lens asphere **#14572** into the horizontal bore. Check belly
   direction against the drawing.
2. Insert the dichroic **#T500spxr (5 × 7 × 1)** into the 45° slot, **coated side
   facing down, toward the objective**.
3. Secure the dichroic with UV glue on the **left and right sides only**. Never
   put adhesive anywhere the beam passes through.
4. Snap the objective asphere **#15273** into the bottom bore of `base_unit`.
   Check belly direction against the drawing. It is not clamped at this stage —
   pressing `objective_unit` (with the plano-convex in it) into the base is what
   finally secures it, so leave it seated and move on. See §5.

### 4.3 `focus_slider_unit` — mirror, emission filter, sensor

1. Insert the mirror **PFR10-P01 (5 × 7 × 1)** from the **rear opening**.
   One tiny droplet of glue.
2. **Seal the rear mirror opening** completely with glue and black paint. It is a
   wide opening and it faces the outside world — untreated, it is the largest
   ambient-light entry point on the scope.
3. Glue the emission filter **#ET525/50m (5 × 5 × 1)** onto the image sensor,
   **coated side away from the sensor**.
4. Glue and blacken around the filter so light can only reach the sensor through
   the coated aperture. Two details that matter here:
   - **Do not cover PCB components** on the sensor board with glue or paint.
   - Run a **≤ 1 mm strip of black paint around the flat face at the edge**, not
     just around the side edge of the filter. The side edge alone leaves a
     shallow path along the glass surface.
5. Insert the sensor (with filter attached) into the top pocket, then **glue and
   black-paint around the inserted sensor** so ambient light cannot enter around
   its perimeter.

---

## 5. Joining the printed parts

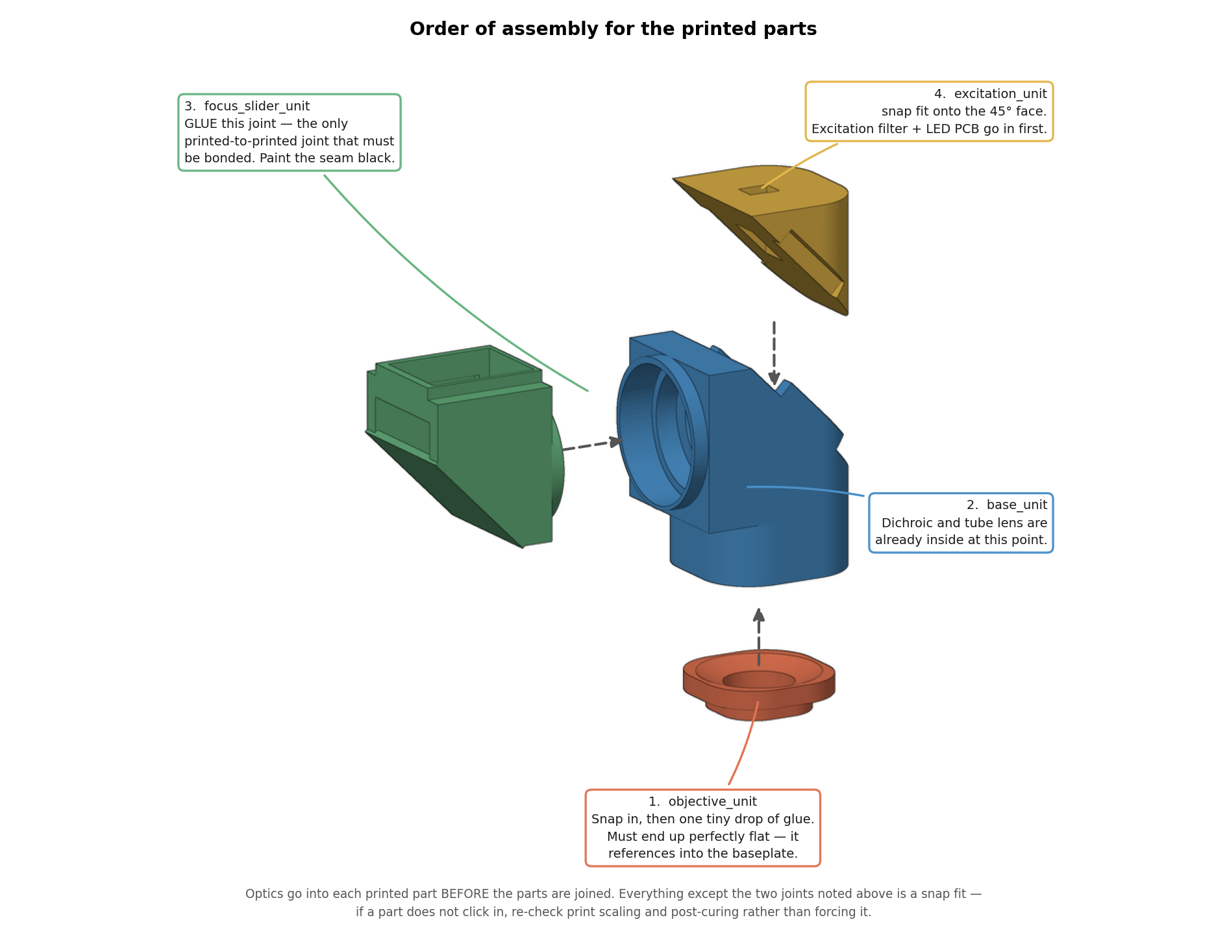
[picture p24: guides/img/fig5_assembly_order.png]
Order of assembly


| Step | Joint | Treatment |
|---|---|---|
| 1 | `objective_unit` → `base_unit` | Holds the plano-convex #45226 and, by pressing home, **also secures the objective asphere #15273 already sitting in the base bore**. Snap in, then **one tiny drop of glue**. Keep it minimal: this part must end up perfectly flat, because it references into the baseplate. |
| 2 | `focus_slider_unit` → `base_unit` | **Glue.** This is the printed-to-printed joint that must be bonded. Black-paint the seam afterwards. |
| 3 | `excitation_unit` → `base_unit` | Snap fit onto the 45° face, then glue **only on the sides where it snaps into the lips / protrusions of `base_unit`**. Keep adhesive off the 45° mating face itself — that face sits directly over the dichroic slot. Black-paint the seam. |

Black paint every external seam once assembled, in thin layers, and let it dry
fully. The scope will often be used in an illuminated room.

---

## 6. Dark-field leak test

Do this **before** the scope goes anywhere near an animal.

1. Point the objective at nothing — a matte black surface, or a closed dark box.
2. Turn the **excitation LED on** at normal imaging power.
3. Acquire frames and look at the background.

Any structured or elevated signal on the sensor is excitation light reaching it
by a path other than the intended one. Trace it and paint it out — a leak here
sets a background floor that costs you SNR on every recording afterwards, and it
cannot be corrected in analysis.

Common culprits, in rough order of likelihood: the excitation filter's lower
edge, the rear mirror opening, the `focus_slider_unit`↔`base_unit` seam, and the
perimeter of the inserted image sensor.

---

## 7. Optics bill of materials

All dimensions in mm. See `img/fig4_optical_layout.png` for spacings.

| Optic | Part number | Size | Unit | Orientation |
|---|---|---|---|---|
| Objective asphere | #15273 | — | `base_unit` (bottom bore) | belly per drawing |
| Plano-convex | #45226 | — | `objective_unit` | 0.1 mm below #15273 |
| Dichroic | #T500spxr | 5 × 7 × 1 | `base_unit` | coated side down |
| Tube lens asphere | #14572 | — | `base_unit` | belly per drawing |
| Mirror | PFR10-P01 | 5 × 7 × 1 | `focus_slider_unit` | 45°, in from rear opening |
| Emission filter | #ET525/50m | 5 × 5 × 1 | `focus_slider_unit` | coated side away from sensor |
| Excitation filter | #ET470/40x | 2 × 2 × 0.5 | `excitation_unit` | coated side up, toward LED |
| Image sensor | #Python480 | — | `focus_slider_unit` | — |
| Excitation LED | LXZ1-PB01 | — | `excitation_unit` | die centred in opening |

## 8. Baseplate hardware

Full details in [`MiniscopeZero/Optics/baseplate/baseplate_components.csv`](../MiniscopeZero/Optics/baseplate/baseplate_components.csv).

The set screw that locks the scope body into the implanted baseplate is
McMaster-Carr **`92311A317`**: an 18-8 stainless steel cup-tip set screw,
**2-64 UNF × 1/8 in long**, headless, **0.035 in (0.9 mm) hex drive**,
Rockwell B80, ASME B18.3, Class 3A fit. Sold in packs of 10.

For the driver we use a **Wiha 263P PicoFinish precision hex screwdriver,
0.9 mm / 0.035 in** (Wiha article `00520`; listed in the US catalog as `26343`,
0.9 mm hex with a 40 mm blade). Nothing depends on that exact model — any
precision driver or L-key that fits the 0.035 in / 0.9 mm hex will do. Do use a
driver that actually matches the hex rather than a Torx or star tip that merely
engages it: baseplate screws get loosened and retightened across sessions, and a
mismatched tip will round the socket out.

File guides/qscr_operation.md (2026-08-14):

## Wireless power transfer cavity operation and assembly

### Drive coil connection
- Connect a coaxial cable to the drive coil.
- Pull the other end of the coaxial cable out of the cavity through the hole in the gold-plated capacitor mount PCB (power input coaxial cable).
- Attach the drive coil to the central pole.
    - **It is attached on the side in the photo, but it is usually better to attach this under the pole.**
    - The drive coil has a magnet embedded and can be attached to the pole using a non-fixed magnet within the pole.

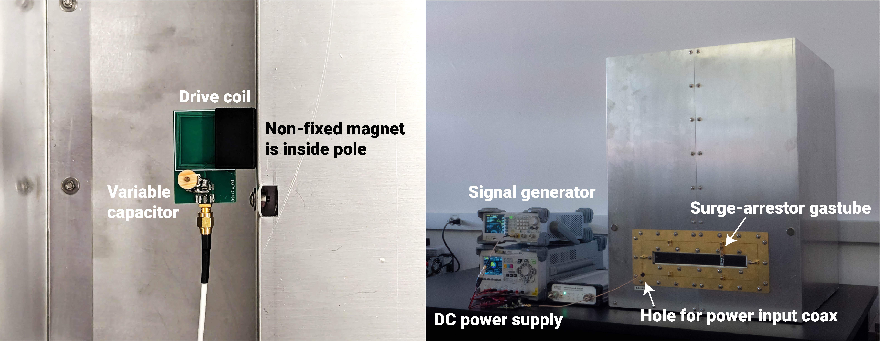
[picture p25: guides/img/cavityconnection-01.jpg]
cavity connection


### RF test/initial tuning
- Plug in the power input coaxial cable to a calibrated VNA (1-port measurement is ok)
- Measure the resonant frequency and Q-factor (optional) of the cavity and tune the drive coil

### [EPC9065](https://epc-co.com/epc/products/evaluation-boards/epc9065) connection

- Short the "Oscillator Disable" header with a jumper pin
- Connect signal generator output to "Oscillator" port
    - Square wave, 5V input (Low: 0V, High: 5V)
    - 6.63 MHz (Best if this can be checked with RF test/tuning)
- Connect DC power (Ch 1) to "Logic Supply" port
    - 10 V, 200 mA limit (should be around 100 mA)
- Connect DC power (Ch 2) to "Main Supply" port
    - This corresponds to DC input power to the cavity
- **Warnings**
    - EPC9065's output coaxial connector is **RP**-SMA (reverse-polarity SMA) so an adapter is needed to interface with standard SMA.
    - EPC9065's output coaxial connector's ground doesn't match with the actual circuit ground.

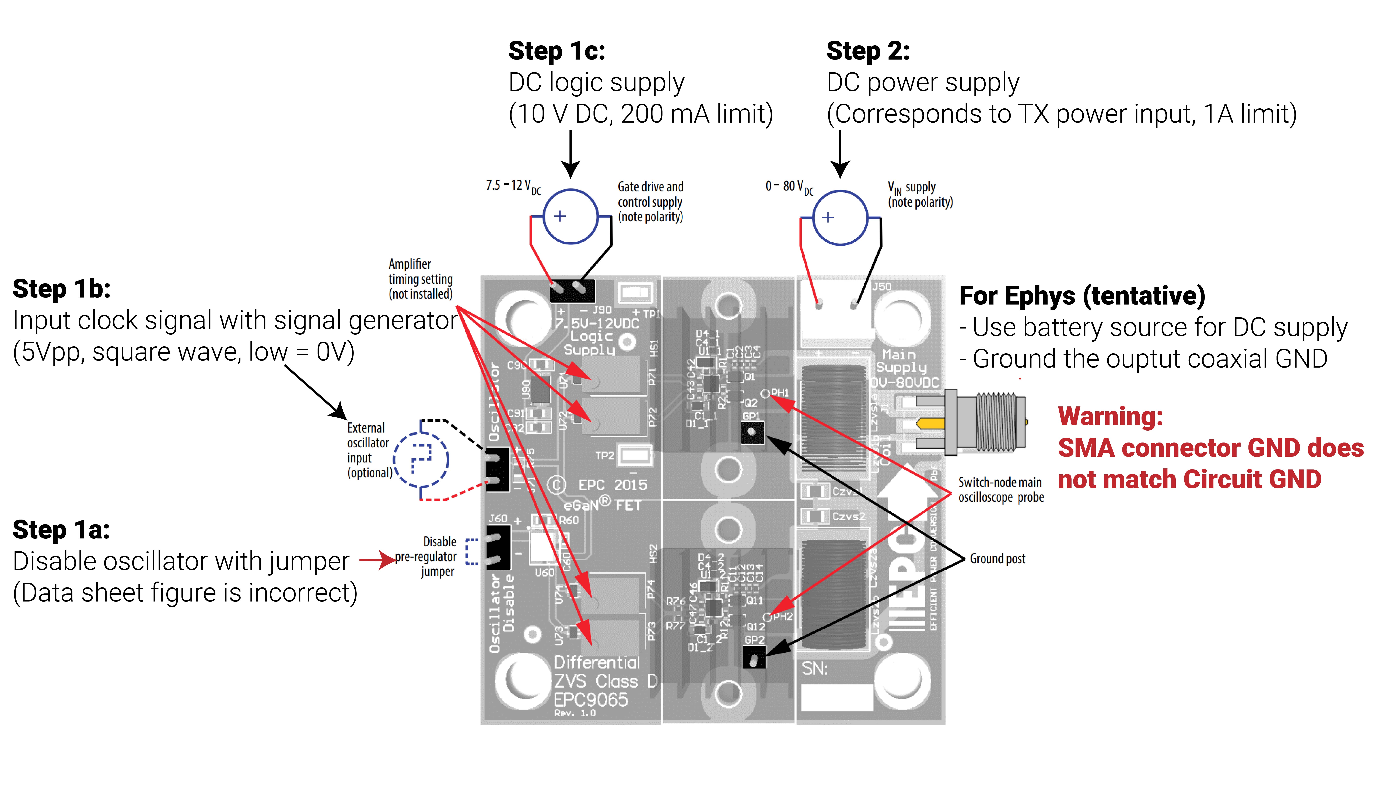
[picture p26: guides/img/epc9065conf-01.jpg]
EPC9065 configuration


### Power ON/OFF sequence
- Turn on signal generator (clock input)
- Turn on DC power logic input channel
- Turn on DC power main supply channel **(wireless power turns ON)**
    - I recommend going from very low power levels and gradually turning up the power input.
        - Example: set a current limit of 0.8 A and gradually turn up voltage starting from 0 V
    - Input impedance changes with operating conditions (*e.g.*, current consumption, device/animal position) so **it is currently necessary to monitor the input power when operating. This will be automated in the future**
- If necessary, check if the cavity is generating magnetic field with the LED demo receiver
- Turn off DC power main supply channel **(wireless power turns OFF)**

## Tips/troubleshooting
### Tuning input impedance
- The input power changes depending on the input impedance, even if the input voltage is static.
- In the current setup, input impedance increases as the drive coil-to-cavity coupling increases.
    - Example: If input power is limited by the voltage limit (*e.g.,* 3 W = [30V, 0.1 A]), decrease the drive coil-to-cavity coupling by misaligning the drive coil. This will increase the input (*e.g.,* 9 W = [30V, 0.3 A])
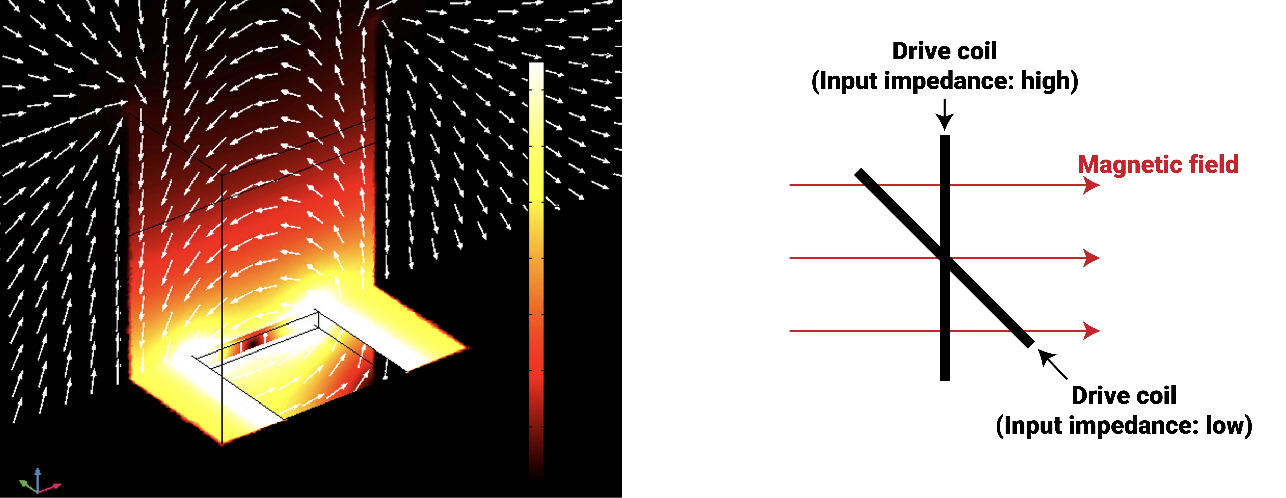
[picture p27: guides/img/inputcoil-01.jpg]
Input impedance adjustment


### T-slotted mounting frames
Frame used for mounting the data receiver, behavior camera, etc.
- List of parts (frames are 20 mm * 20 mm)
    - 525 mm * 2
    - 480 mm * 4
    - 700 mm * 4
    - Corner brackets
    - Edge caps

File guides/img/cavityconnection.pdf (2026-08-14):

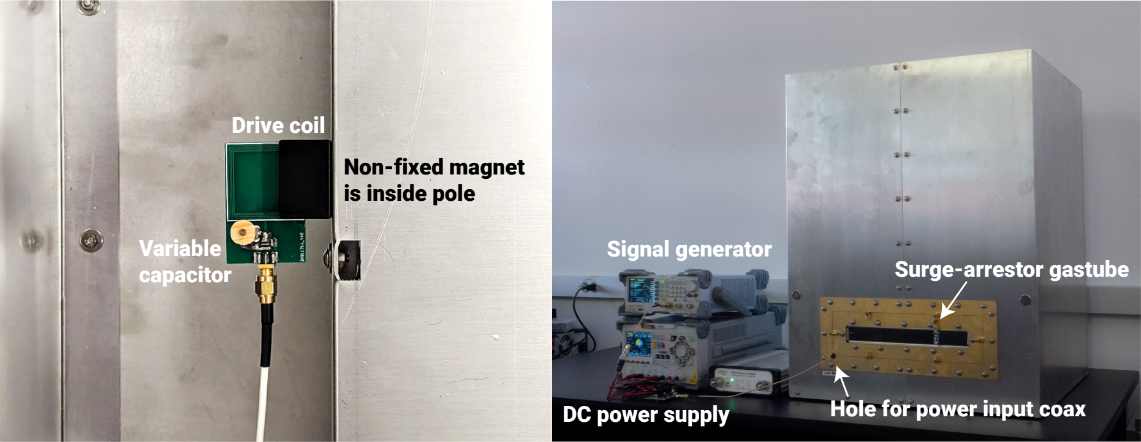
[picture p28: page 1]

Drive coil

Variable
capacitor

Hole for power input coax

Signal generator

DC power supply

Non-fixed magnet
is inside pole

Surge-arrestor gastube

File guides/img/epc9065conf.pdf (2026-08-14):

Step 1c:
DC logic supply
(10 V DC, 200 mA limit)
Step 1b:

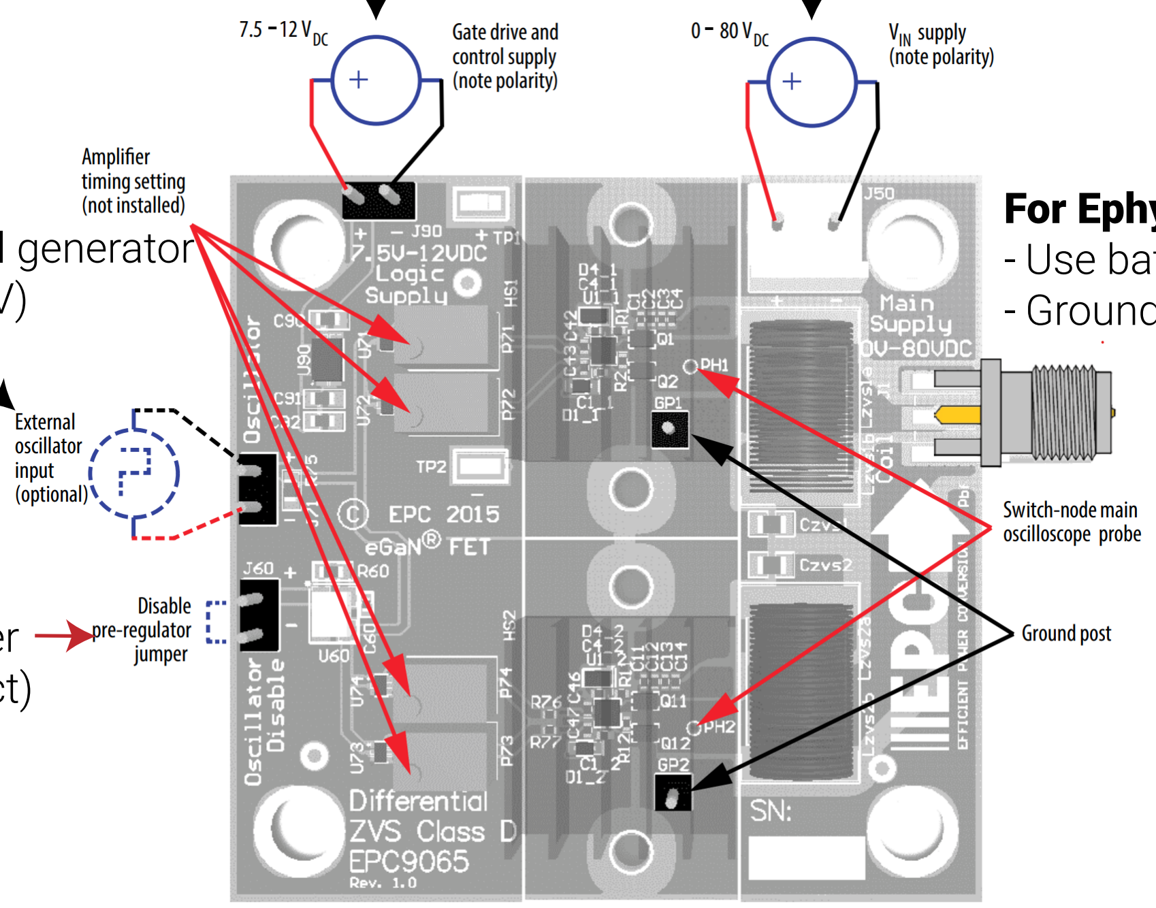
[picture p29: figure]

Input clock signal with signal generator (5Vpp, square wave, low = 0V)

Step 1a:
Disable oscillator with jumper (Data sheet figure is incorrect)
Step 2:
DC power supply
(Corresponds to TX power input, 1A limit)

For Ephys (tentative)
- Use battery source for DC supply
- Ground the ouptut coaxial GND Warning:
SMA connector GND does
not match Circuit GND

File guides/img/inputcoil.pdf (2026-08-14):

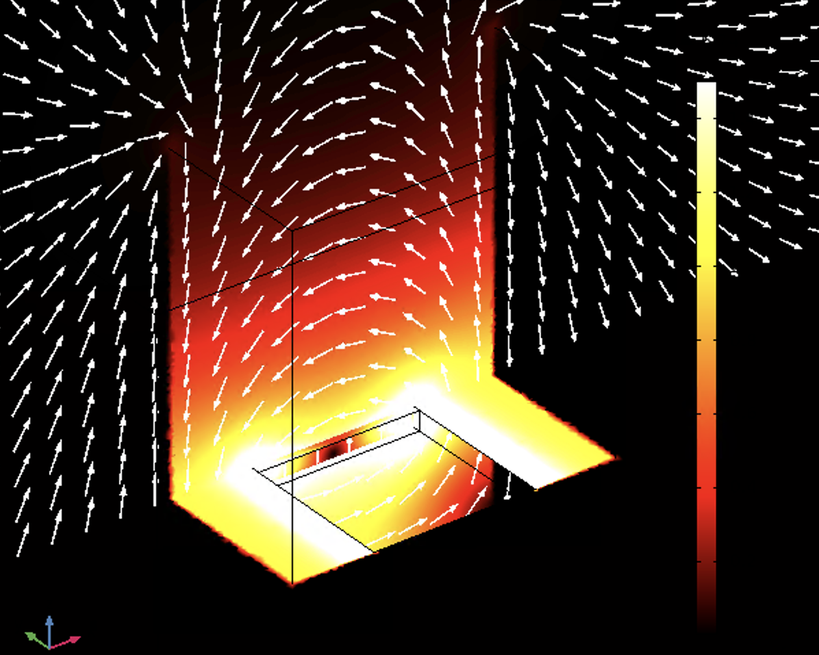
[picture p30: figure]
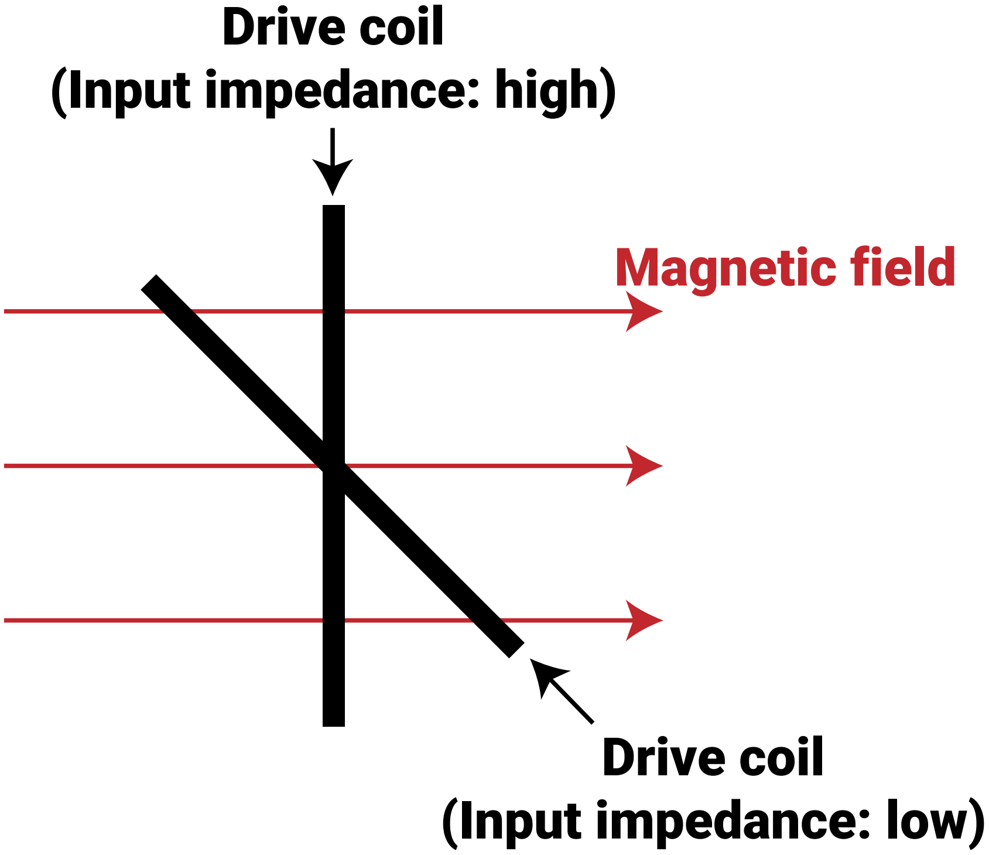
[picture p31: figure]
Magnetic field; Drive coil (Input impedance: high); Drive coil (Input impedance: low)

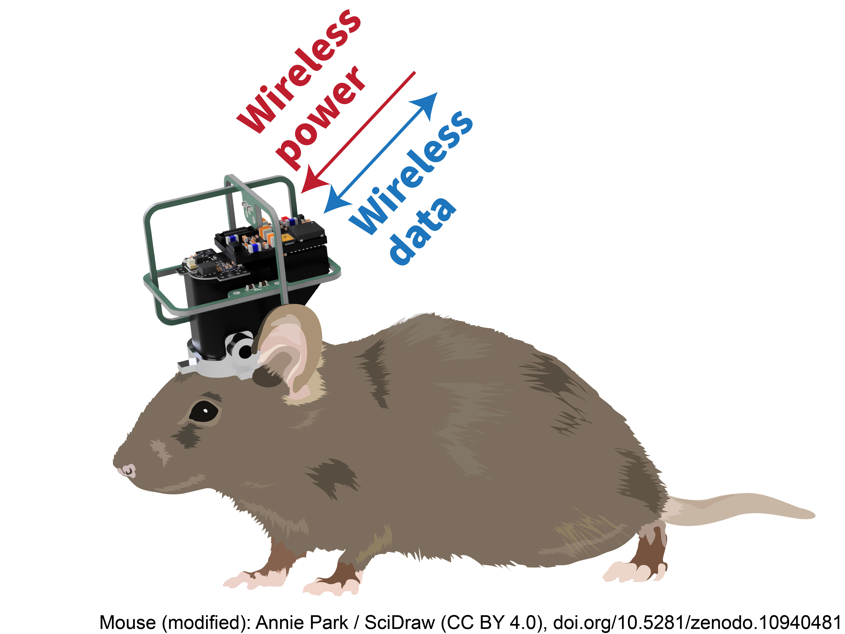
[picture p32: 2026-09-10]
guides/img/minizero_thumbnail.jpg

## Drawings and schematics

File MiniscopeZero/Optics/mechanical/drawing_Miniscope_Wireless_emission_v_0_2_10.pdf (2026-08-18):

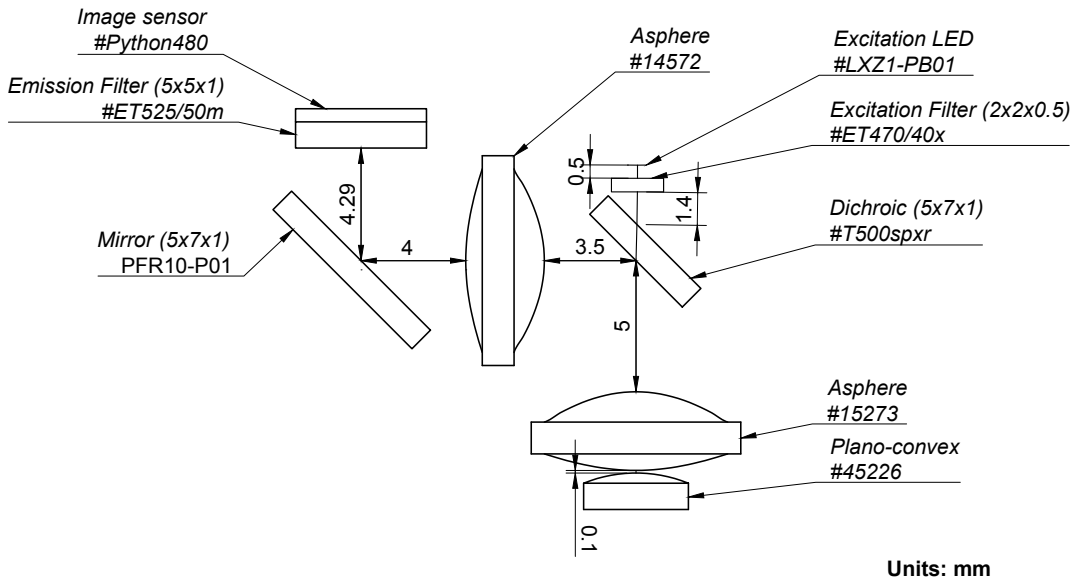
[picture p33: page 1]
Asphere #15273; Plano-convex #45226 0.1; Dichroic (5x7x1) #T500spxr 3.5; Asphere #14572; Mirror (5x7x1); PFR10-P01; Emission Filter (5x5x1) #ET525/50m; Units: mm; Image sensor #Python480; Excitation Filter (2x2x0.5) #ET470/40x; Excitation LED #LXZ1-PB01 1.4 0.5

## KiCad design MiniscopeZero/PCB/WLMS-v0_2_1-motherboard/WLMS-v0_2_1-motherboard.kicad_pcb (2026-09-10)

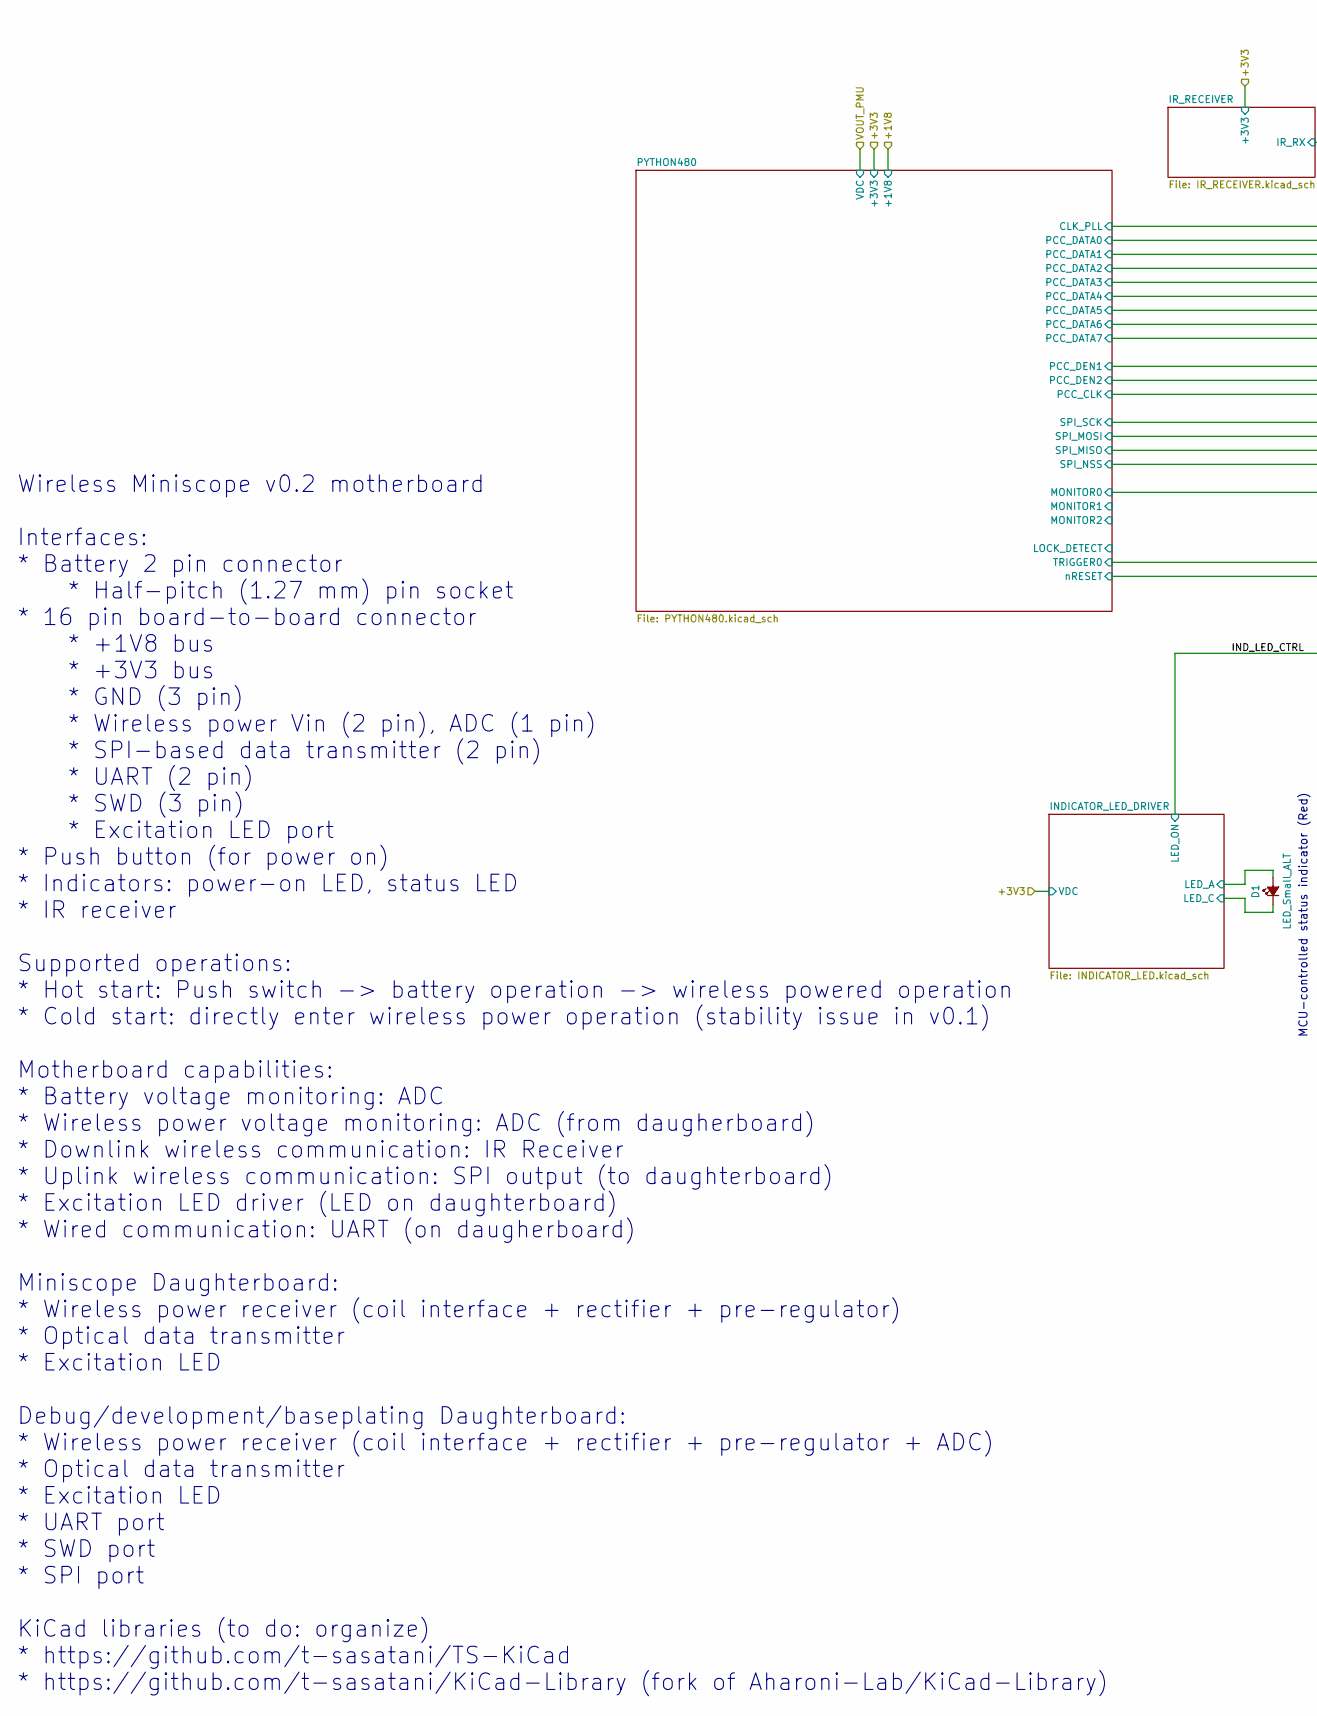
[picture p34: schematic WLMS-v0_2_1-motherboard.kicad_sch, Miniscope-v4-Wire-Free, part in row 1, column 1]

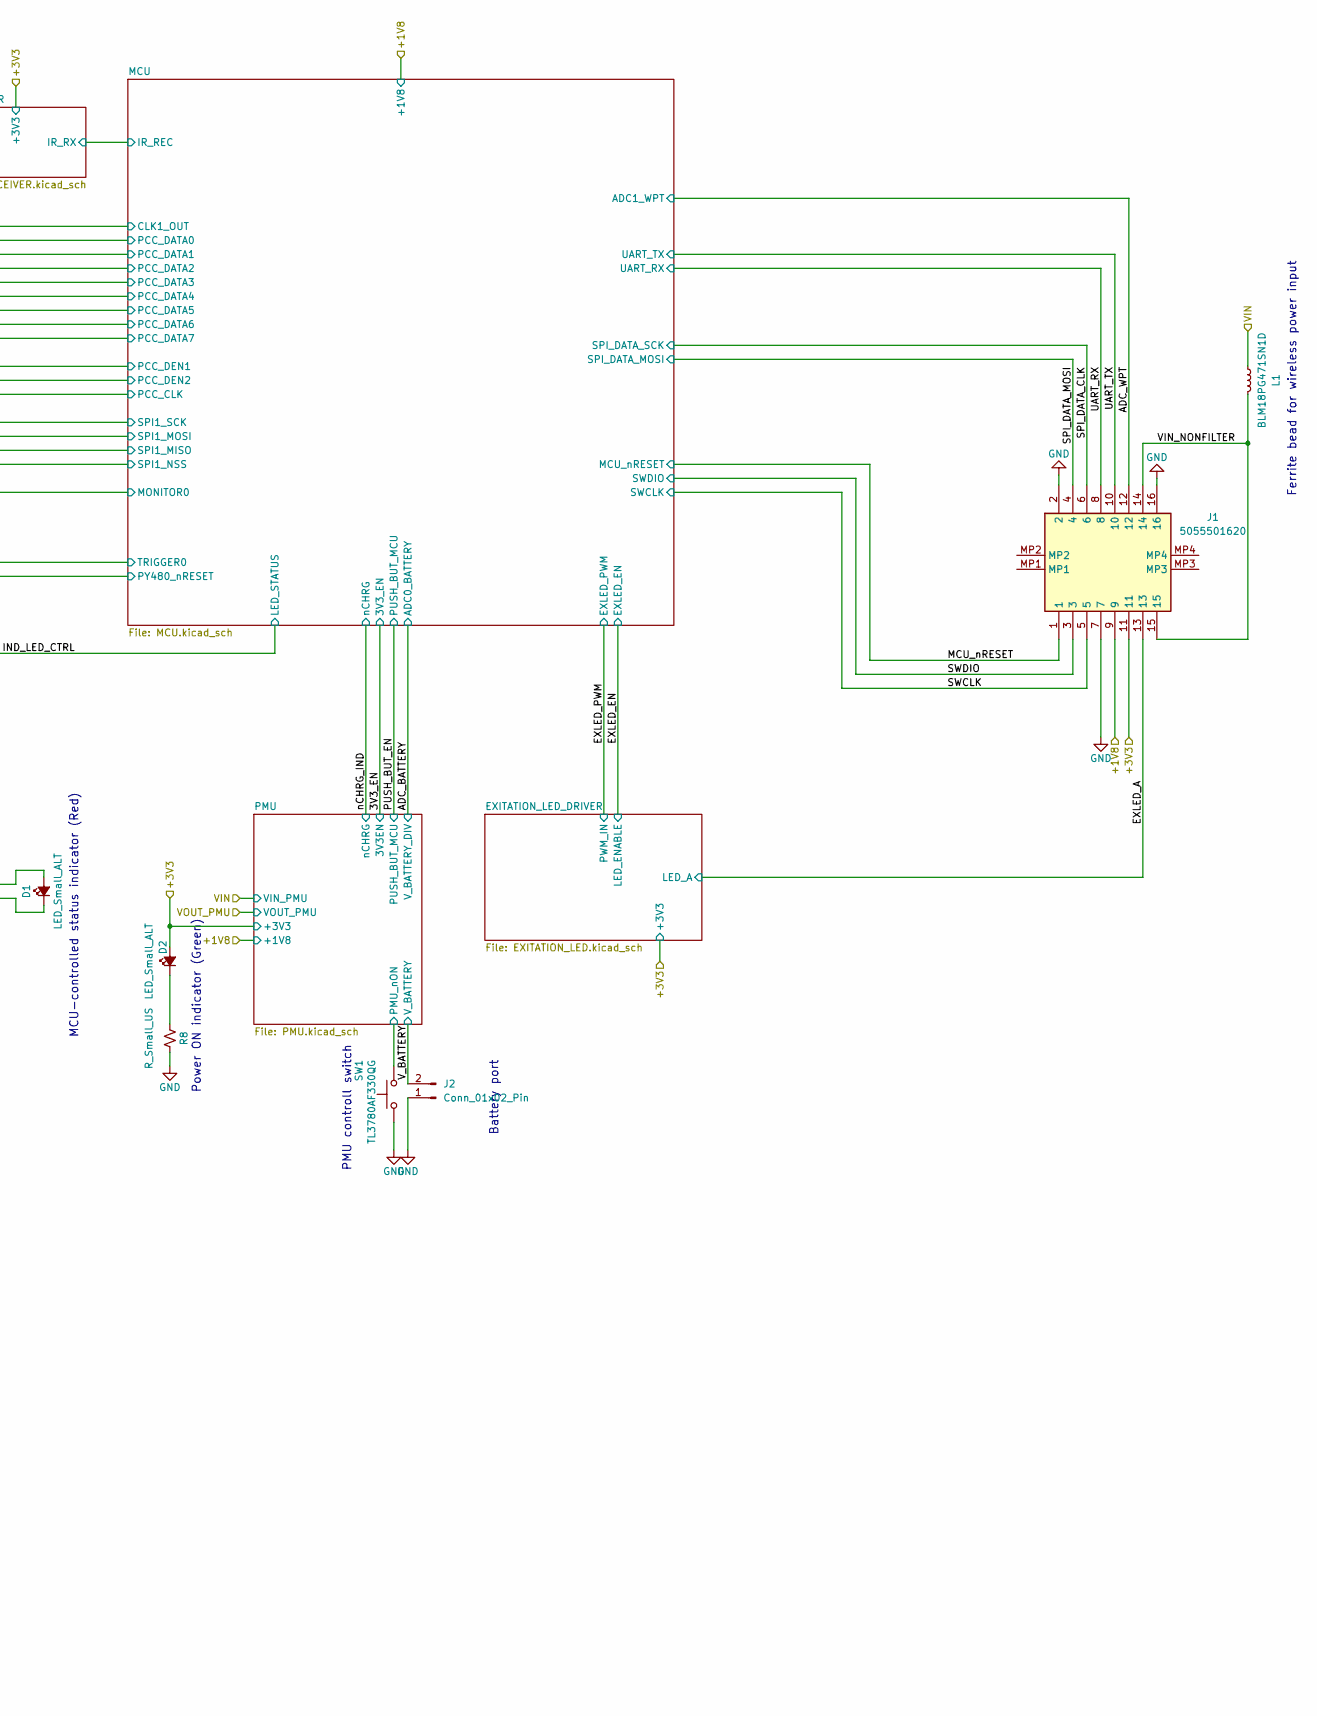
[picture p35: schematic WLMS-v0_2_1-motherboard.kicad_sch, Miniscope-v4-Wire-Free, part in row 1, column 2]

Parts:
D1, D2: LED_Small_ALT; LED_SC80X160X65L40L
J1: 5055501620; Manufacturer_Part_Number 5055501620
J2: Conn_01x02_Pin; PinHeader_1x02_P1.00mm_Vertical
L1: BLM18PG471SN1D; L_0603_1608Metric_L; Manufacturer_Part_Number BLM18PG471SN1D
R8: R_Small_US; R_0201_0603Metric_ERJ_L
SW1: TL3780AF330QG; SMD-Switch-3mmx2mm; Manufacturer_Part_Number TL3780AF330QG

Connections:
/+1V8: J1.9; also elsewhere on the board
/+3V3: D2.2 (A), J1.11; also elsewhere on the board
/ADC_WPT: J1.12; also elsewhere on the board
/EXLED_A: J1.13; also elsewhere on the board
/INDICATOR_LED_DRIVER/LED_A: D1.2 (A); also elsewhere on the board
/INDICATOR_LED_DRIVER/LED_C: D1.1 (K); also elsewhere on the board
/MCU_nRESET: J1.1; also elsewhere on the board
/PMU/PMU_nON: SW1.2; also elsewhere on the board
/SPI_DATA_CLK: J1.6; also elsewhere on the board
/SPI_DATA_MOSI: J1.4; also elsewhere on the board
/SWCLK: J1.5; also elsewhere on the board
/SWDIO: J1.3; also elsewhere on the board
/UART_RX: J1.8; also elsewhere on the board
/UART_TX: J1.10; also elsewhere on the board
/VIN: L1.1; also elsewhere on the board
/VIN_NONFILTER: J1.14, J1.15, L1.2
/V_BATTERY: J2.2; also elsewhere on the board
GND: J1.2, J1.7, J1.16, J2.1, R8.1, SW1.1; also elsewhere on the board
unnamed: D2.1 (K), R8.2

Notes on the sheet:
Ferrite bead for wireless power input
Battery port
Power ON indicator (Green)
PMU controll switch
MCU-controlled status indicator (Red)
Wireless Miniscope v0.2 motherboard Interfaces: * Battery 2 pin connector * Half-pitch (1.27 mm) pin socket * 16 pin board-to-board connector * +1V8 bus * +3V3 bus * GND (3 pin) * Wireless power Vin (2 pin), ADC (1 pin) * SPI-based data transmitter (2 pin) * UART (2 pin) * SWD (3 pin) * Excitation 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

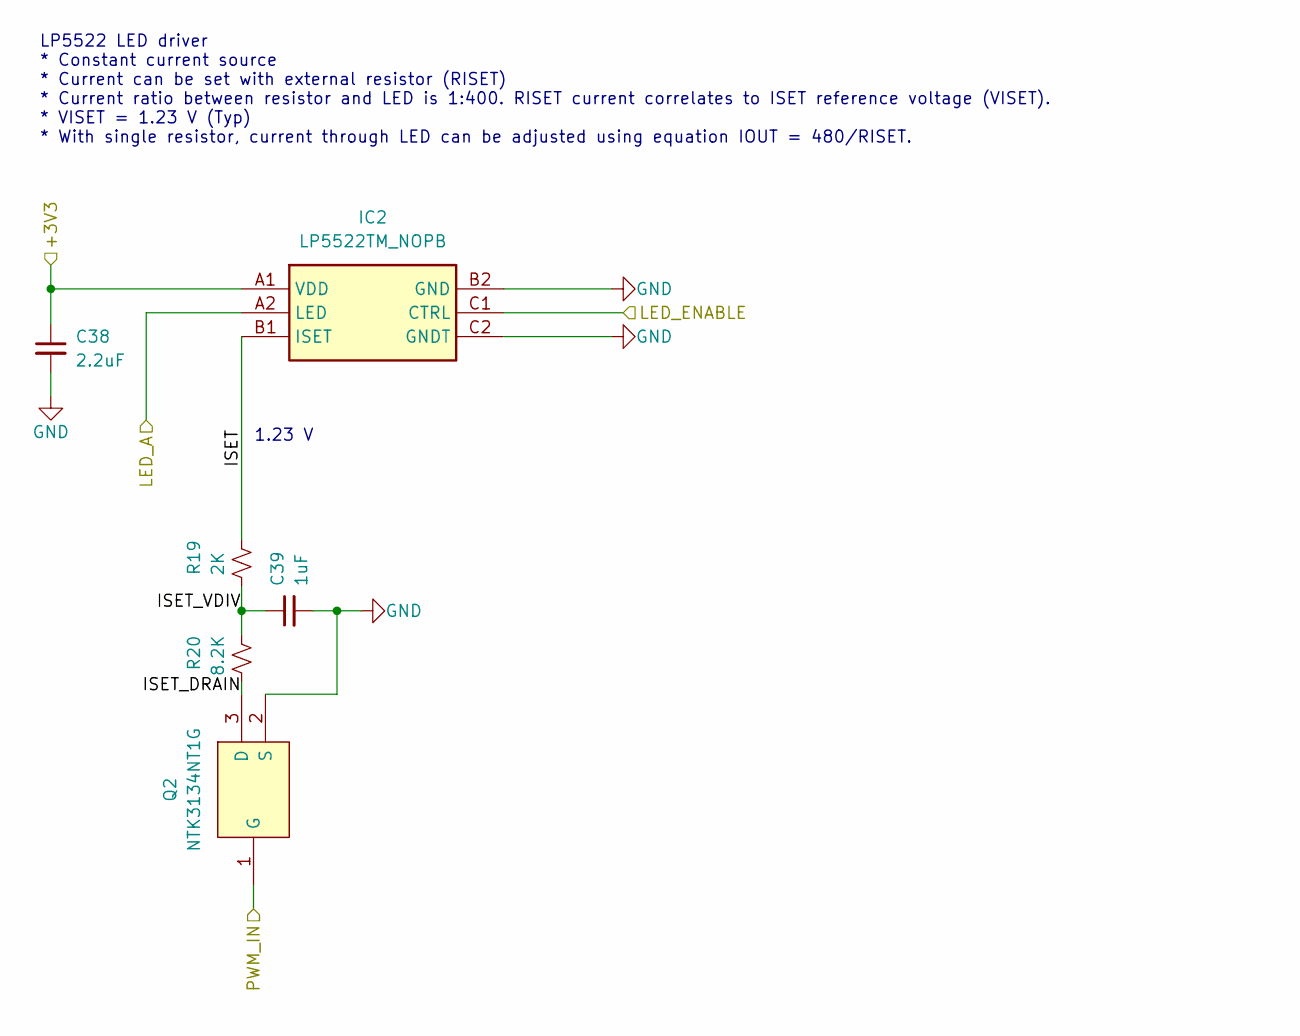
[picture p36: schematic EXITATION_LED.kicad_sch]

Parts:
C38: 2.2uF; C_0201_0603Metric_L; Manufacturer_Part_Number GRM033R61A225KE47D
C39: 1uF; C_0201_0603Metric_L; Manufacturer_Part_Number GRM033R61A105ME15D
IC2: LP5522TM_NOPB; BGA6C40P2X3_81X121X68; Manufacturer_Part_Number LP5522TM/NOPB; Mouser Part Number 926-LP5522TM/NOPB
Q2: NTK3134NT1G; TRXSOFL3P40_120X120X55L29X21L; Manufacturer_Part_Number NTK3134NT1G; Mouser Part Number 863-NTK3134NT1G
R19: 2K; R_0201_0603Metric_ERJ_L; Manufacturer_Part_Number CRCW02012K00FNED
R20: 8.2K; R_0201_0603Metric_ERJ_L; Manufacturer_Part_Number CRCW02018K20FKED

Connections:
/+3V3: C38.1, IC2.A1 (VDD); also elsewhere on the board
/EXITATION_LED_DRIVER/ISET: IC2.B1 (ISET), R19.1
/EXITATION_LED_DRIVER/ISET_DRAIN: Q2.3 (D), R20.2
/EXITATION_LED_DRIVER/ISET_VDIV: C39.1, R19.2, R20.1
/EXLED_A: IC2.A2 (LED); also elsewhere on the board
/EXLED_EN: IC2.C1 (CTRL); also elsewhere on the board
/EXLED_PWM: Q2.1 (G); also elsewhere on the board
GND: C38.2, C39.2, IC2.B2 (GND), IC2.C2 (GNDT), Q2.2 (S); also elsewhere on the board

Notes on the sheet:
1.23 V
LP5522 LED driver * Constant current source * Current can be set with external resistor (RISET) * Current ratio between resistor and LED is 1:400. RISET current correlates to ISET reference voltage (VISET). * VISET = 1.23 V (Typ) * With single resistor, current through LED can be adjusted using equ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

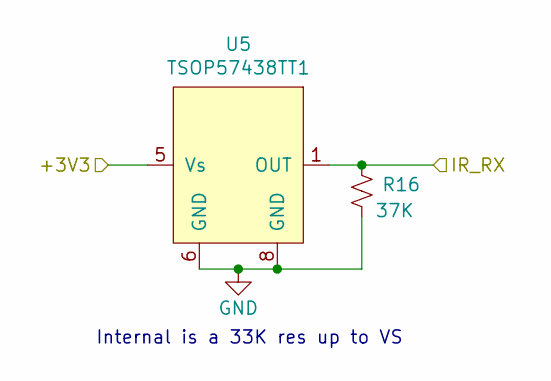
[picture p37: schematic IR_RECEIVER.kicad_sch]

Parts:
R16: 37K; R_0201_0603Metric_ERJ_L; Manufacturer_Part_Number ERJ-1GNF3742C
U5: TSOP57438TT1; SON_4_P300_395X395X90L55X35L; Manufacturer_Part_Number TSOP57438TT1

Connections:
/+3V3: U5.5 (Vs); also elsewhere on the board
/IR_RECEIVER/IR_RX: R16.1, U5.1 (OUT); also elsewhere on the board
GND: R16.2, U5.6 (GND), U5.8 (GND); also elsewhere on the board

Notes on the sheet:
Internal is a 33K res up to VS

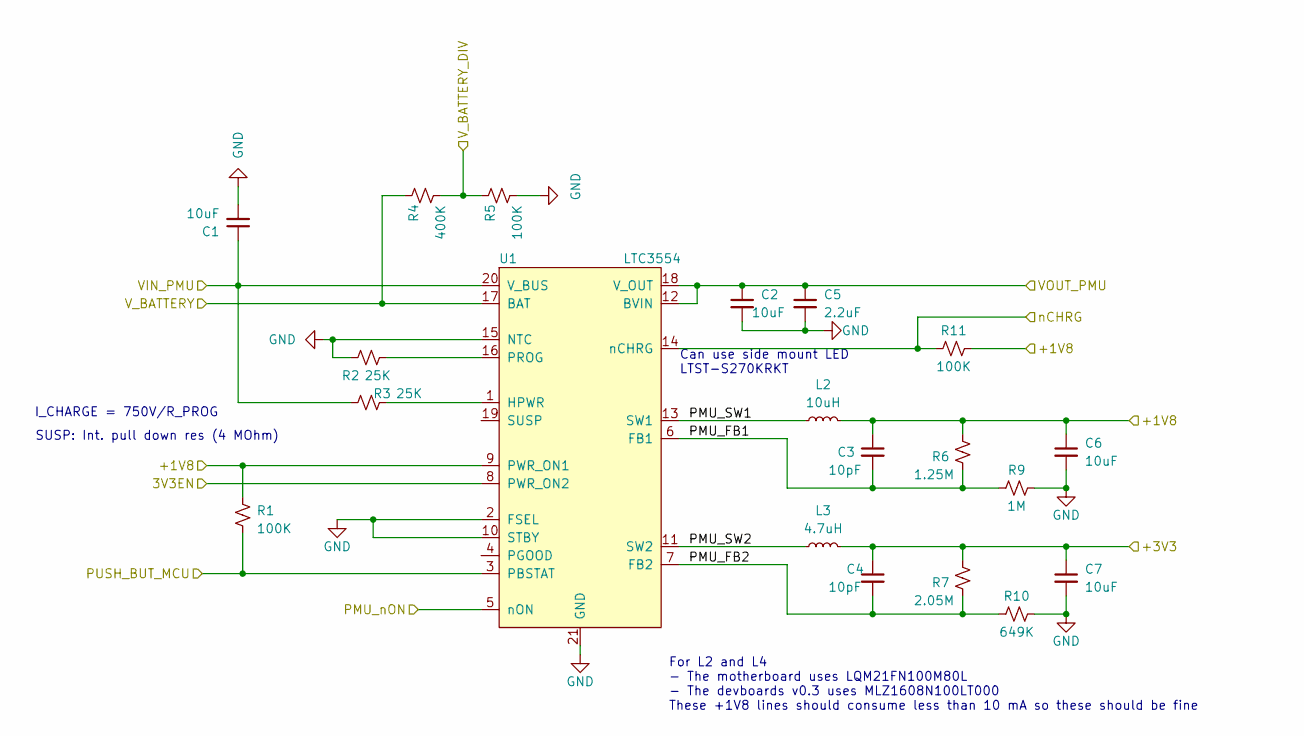
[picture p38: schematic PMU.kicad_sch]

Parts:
C1, C2, C6, C7: 10uF; C_0402_1005Metric_L; Manufacturer_Part_Number GRM155R60J106ME15D
C3, C4: 10pF; C_0201_0603Metric_L; Manufacturer_Part_Number GRM0335C1H100FA01J
C5: 2.2uF; C_0201_0603Metric_L; Manufacturer_Part_Number GRM033R61A225KE47D
L2: 10uH; C_0805_2012Metric_L; Manufacturer_Part_Number MLZ1608N100LT000
L3: 4.7uH; C_0805_2012Metric_L; Manufacturer_Part_Number ASMCI-0805-4R7M-T
R1, R5, R11: 100K; R_0201_0603Metric_ERJ_L; Manufacturer_Part_Number ERJ-1GNF1003C
R2, R3: 25K; R_0201_0603Metric_ERJ_L; Manufacturer_Part_Number CRCW020124K9FNED
R4: 400K; R_0201_0603Metric_ERJ_L; Manufacturer_Part_Number ERJ-1GNF4023C
R6: 1.25M; R_0201_0603Metric_ERJ_L; Manufacturer_Part_Number CRCW02011M27FNED
R7: 2.05M; R_0201_0603Metric_ERJ_L; Manufacturer_Part_Number CRCW02012M05FNED
R9: 1M; R_0201_0603Metric_ERJ_L; Manufacturer_Part_Number CRCW02011M00FNED
R10: 649K; R_0201_0603Metric_ERJ_L; Manufacturer_Part_Number CRCW0201649KFNED
U1: LTC3554; QFN-20-1EP_3x3mm_P0.4mm_EP1.65x1.65mm; Manufacturer_Part_Number LTC3554EUD#PBF

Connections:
/3V3_EN: U1.8 (PWR_ON2); also elsewhere on the board
/+1V8: C3.1, C6.1, L2.2, R1.1, R6.1, R11.1, U1.9 (PWR_ON1); also elsewhere on the board
/+3V3: C4.1, C7.1, L3.2, R7.1; also elsewhere on the board
/ADC_BATTERY: R4.2, R5.1; also elsewhere on the board
/PMU/PMU_FB1: C3.2, R6.2, R9.2, U1.6 (FB1)
/PMU/PMU_FB2: C4.2, R7.2, R10.2, U1.7 (FB2)
/PMU/PMU_SW1: L2.1, U1.13 (SW1)
/PMU/PMU_SW2: L3.1, U1.11 (SW2)
/PMU/PMU_nON: U1.5 (nON); also elsewhere on the board
/PUSH_BUT_EN: R1.2, U1.3 (PBSTAT); also elsewhere on the board
/VIN: C1.1, R3.2, U1.20 (V_BUS); also elsewhere on the board
/VOUT_PMU: C2.1, C5.1, U1.12 (BVIN), U1.18 (V_OUT); also elsewhere on the board
/V_BATTERY: R4.1, U1.17 (BAT); also elsewhere on the board
/nCHRG_IND: R11.2, U1.14 (nCHRG); also elsewhere on the board
GND: C1.2, C2.2, C5.2, C6.2, C7.2, R2.2, R5.2, R9.1, R10.1, U1.2 (FSEL), U1.10 (STBY), U1.15 (NTC), U1.21 (GND); also elsewhere on the board
unnamed: R3.1, U1.1 (HPWR)
unnamed: R2.1, U1.16 (PROG)

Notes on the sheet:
For L2 and L4 - The motherboard uses LQM21FN100M80L - The devboards v0.3 uses MLZ1608N100LT000 These +1V8 lines should consume less than 10 mA so these should be fine
SUSP: Int. pull down res (4 MOhm)
Can use side mount LED LTST-S270KRKT
I_CHARGE = 750V/R_PROG

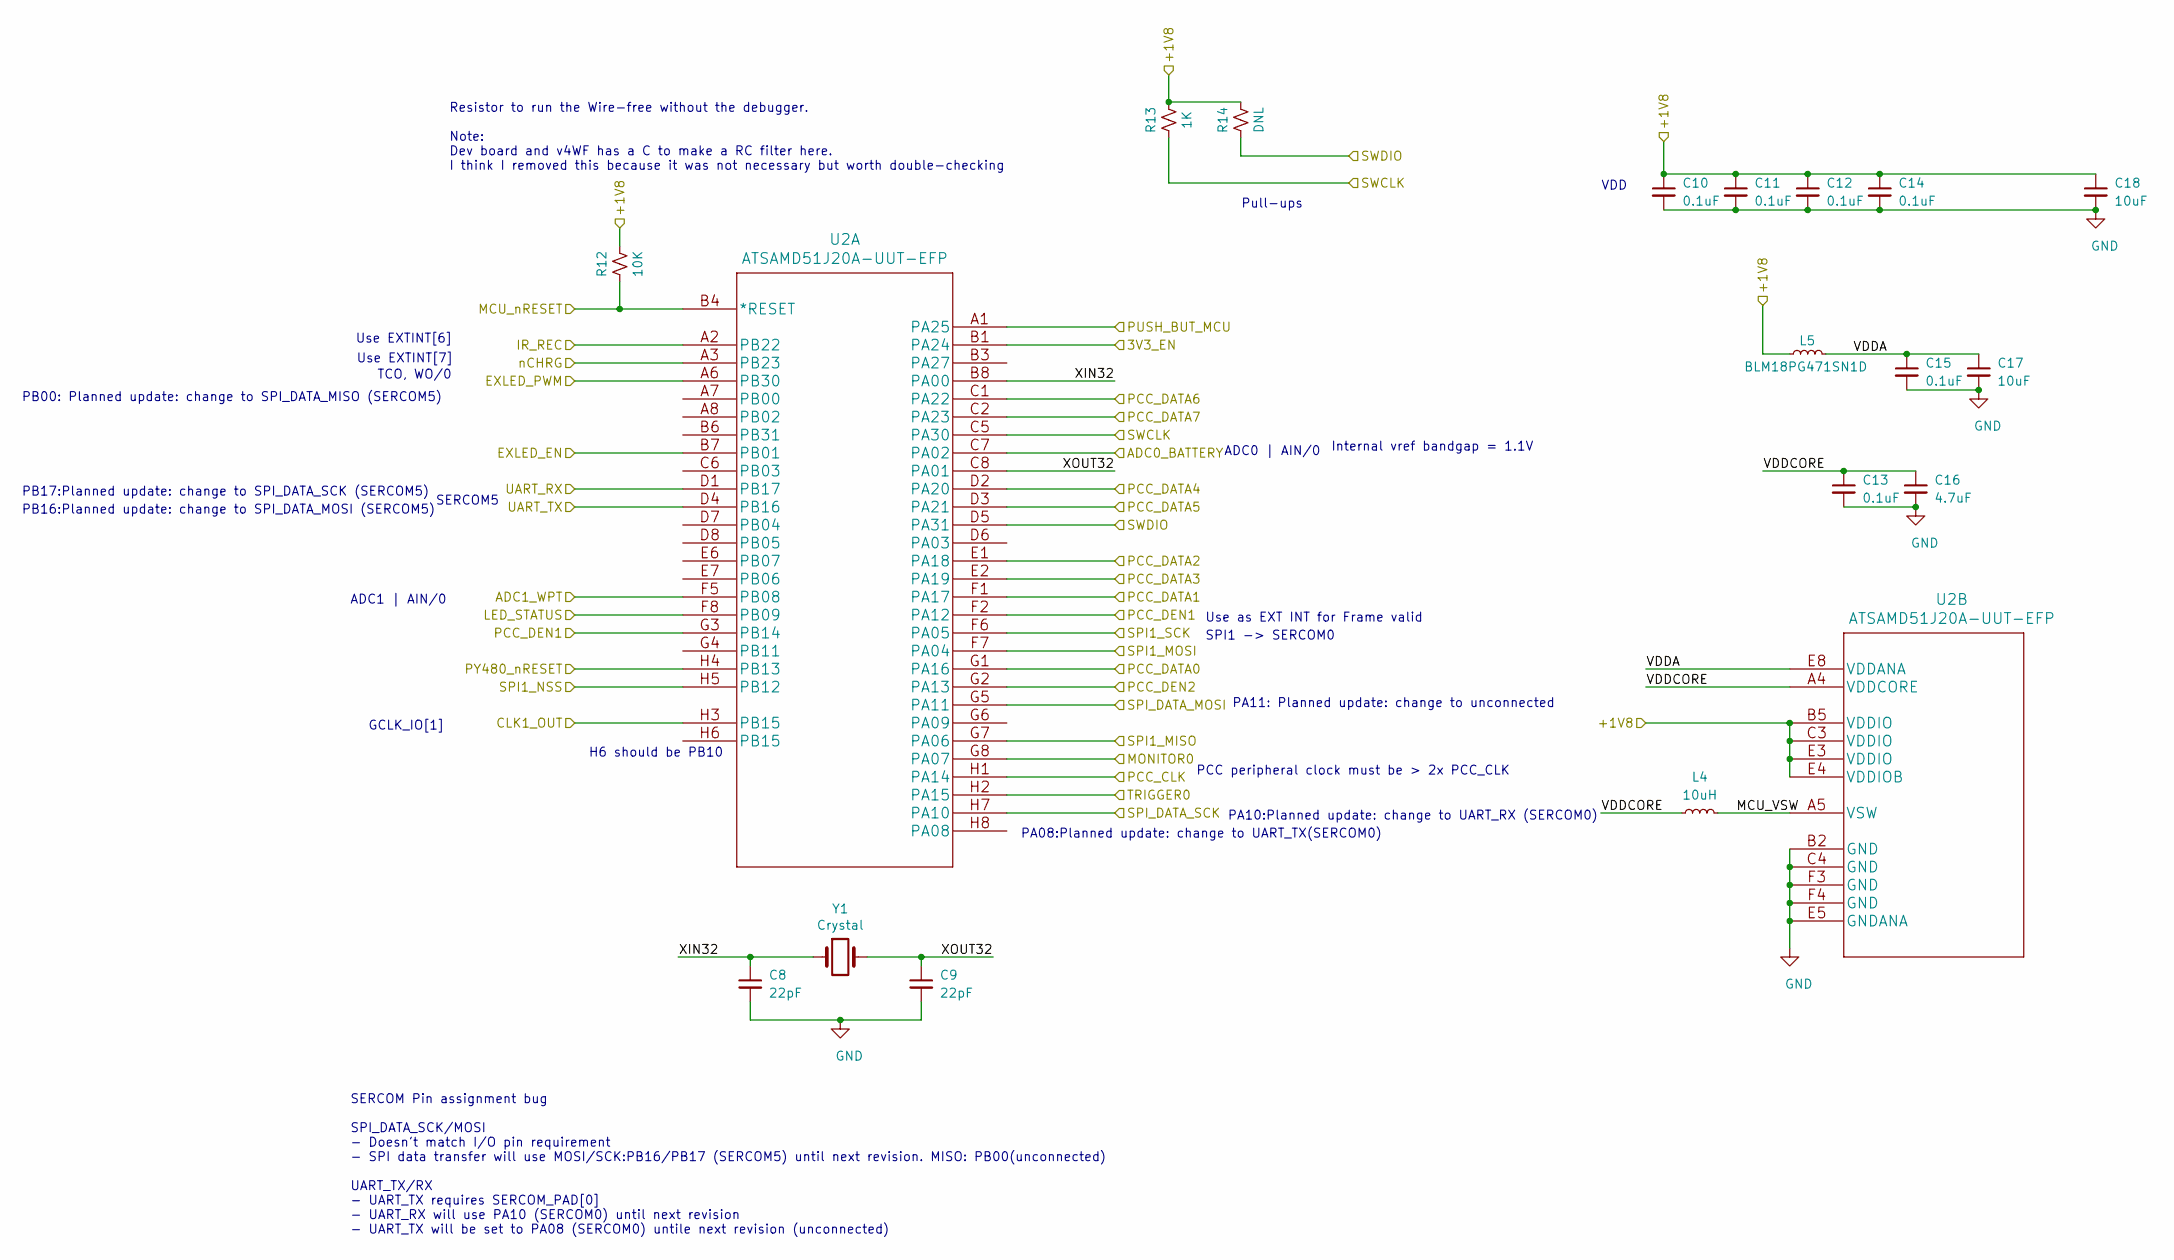
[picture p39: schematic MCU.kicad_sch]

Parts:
C8, C9: 22pF; C_0201_0603Metric_L; Manufacturer_Part_Number GRM0335C1H220GA01D
C10, C11, C12, C13, C14, C15: 0.1uF; C_0201_0603Metric_L; Manufacturer_Part_Number GRM033R61E104KE14J
C16: 4.7uF; C_0201_0603Metric_L; Manufacturer_Part_Number GRM035R60J475ME15D
C17, C18: 10uF; C_0402_1005Metric_L; Manufacturer_Part_Number GRM155R60J106ME15D
L4: 10uH; C_0805_2012Metric_L; Manufacturer_Part_Number MLZ1608N100LT000
L5: BLM18PG471SN1D; L_0603_1608Metric_L; Manufacturer_Part_Number BLM18PG471SN1D
R12: 10K; R_0201_0603Metric_ERJ_L; Manufacturer_Part_Number CRCW02011K00FKED
R13: 1K; R_0201_0603Metric_ERJ_L; Manufacturer_Part_Number CRCW02011K00FKED
R14: DNL; R_0201_0603Metric_ERJ_L; Manufacturer_Part_Number DNL
U2: ATSAMD51J20A-UUT-EFP; Manufacturer_Part_Number ATSAMD51J20A-UUT-EFP
Y1: Crystal; Crystal_SMD_MicroCrystal_CC8V-T1A-2Pin_2.0x1.2mm

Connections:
/3V3_EN: U2.B1 (PA24); also elsewhere on the board
/+1V8: C10.1, C11.1, C12.1, C14.1, C18.1, L5.1, R12.1, R13.1, R14.1, U2.B5 (VDDIO), U2.C3 (VDDIO), U2.E3 (VDDIO), U2.E4 (VDDIOB); also elsewhere on the board
/ADC_BATTERY: U2.C7 (PA02); also elsewhere on the board
/ADC_WPT: U2.F5 (PB08); also elsewhere on the board
/EXLED_EN: U2.B7 (PB01); also elsewhere on the board
/EXLED_PWM: U2.A6 (PB30); also elsewhere on the board
/IND_LED_CTRL: U2.F8 (PB09); also elsewhere on the board
/IR_RECEIVER/IR_RX: U2.A2 (PB22); also elsewhere on the board
/MCU/CLK1_OUT: U2.H3 (PB15); also elsewhere on the board
/MCU/MCU_VSW: L4.2, U2.A5 (VSW)
/MCU/PCC_CLK: U2.H1 (PA14); also elsewhere on the board
/MCU/PCC_DATA0: U2.G1 (PA16); also elsewhere on the board
/MCU/PCC_DATA1: U2.F1 (PA17); also elsewhere on the board
/MCU/PCC_DATA2: U2.E1 (PA18); also elsewhere on the board
/MCU/PCC_DATA3: U2.E2 (PA19); also elsewhere on the board
/MCU/PCC_DATA4: U2.D2 (PA20); also elsewhere on the board
/MCU/PCC_DATA5: U2.D3 (PA21); also elsewhere on the board
/MCU/PCC_DATA6: U2.C1 (PA22); also elsewhere on the board
/MCU/PCC_DATA7: U2.C2 (PA23); also elsewhere on the board
/MCU/PCC_DEN1: U2.F2 (PA12), U2.G3 (PB14); also elsewhere on the board
/MCU/PCC_DEN2: U2.G2 (PA13); also elsewhere on the board
/MCU/SPI1_MISO: U2.G7 (PA06); also elsewhere on the board
/MCU/SPI1_MOSI: U2.F7 (PA04); also elsewhere on the board
/MCU/SPI1_NSS: U2.H5 (PB12); also elsewhere on the board
/MCU/SPI1_SCK: U2.F6 (PA05); also elsewhere on the board
/MCU/VDDA: C15.1, C17.1, L5.2, U2.E8 (VDDANA)
/MCU/VDDCORE: C13.1, C16.1, L4.1, U2.A4 (VDDCORE)
/MCU/XIN32: C8.1, U2.B8 (PA00), Y1.1
/MCU/XOUT32: C9.1, U2.C8 (PA01), Y1.2
/MCU_nRESET: R12.2, U2.B4 (*RESET); also elsewhere on the board
/PUSH_BUT_EN: U2.A1 (PA25); also elsewhere on the board
/PYTHON480/MONITOR0: U2.G8 (PA07); also elsewhere on the board
/PYTHON480/RESET_N: U2.H4 (PB13); also elsewhere on the board
/PYTHON480/TRIGGER0: U2.H2 (PA15); also elsewhere on the board
/SPI_DATA_CLK: U2.H7 (PA10); also elsewhere on the board
/SPI_DATA_MOSI: U2.G5 (PA11); also elsewhere on the board
/SWCLK: R13.2, U2.C5 (PA30); also elsewhere on the board
/SWDIO: R14.2, U2.D5 (PA31); also elsewhere on the board
/UART_RX: U2.D1 (PB17); also elsewhere on the board
/UART_TX: U2.D4 (PB16); also elsewhere on the board
/nCHRG_IND: U2.A3 (PB23); also elsewhere on the board
GND: C8.2, C9.2, C10.2, C11.2, C12.2, C13.2, C14.2, C15.2, C16.2, C17.2, C18.2, U2.B2 (GND), U2.C4 (GND), U2.E5 (GNDANA), U2.F3 (GND), U2.F4 (GND); also elsewhere on the board

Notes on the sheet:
Use EXTINT[6]
ADC1 | AIN/0
GCLK_IO[1]
Pull-ups
SPI1 -> SERCOM0
SERCOM5
TCO, WO/0
PB17:Planned update: change to SPI_DATA_SCK (SERCOM5)
PB16:Planned update: change to SPI_DATA_MOSI (SERCOM5)
SERCOM Pin assignment bug SPI_DATA_SCK/MOSI - Doesn't match I/O pin requirement - SPI data transfer will use MOSI/SCK:PB16/PB17 (SERCOM5) until next revision. MISO: PB00(unconnected) UART_TX/RX - UART_TX requires SERCOM_PAD[0] - UART_RX will use PA10 (SERCOM0) until next revision - UART_TX will be 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
VDD
Use as EXT INT for Frame valid
PA10:Planned update: change to UART_RX (SERCOM0)
PA11: Planned update: change to unconnected
Use EXTINT[7]
ADC0 | AIN/0
PB00: Planned update: change to SPI_DATA_MISO (SERCOM5)
PA08:Planned update: change to UART_TX(SERCOM0)
PCC peripheral clock must be > 2x PCC_CLK
Resistor to run the Wire-free without the debugger. Note: Dev board and v4WF has a C to make a RC filter here. I think I removed this because it was not necessary but worth double-checking
Internal vref bandgap = 1.1V
H6 should be PB10

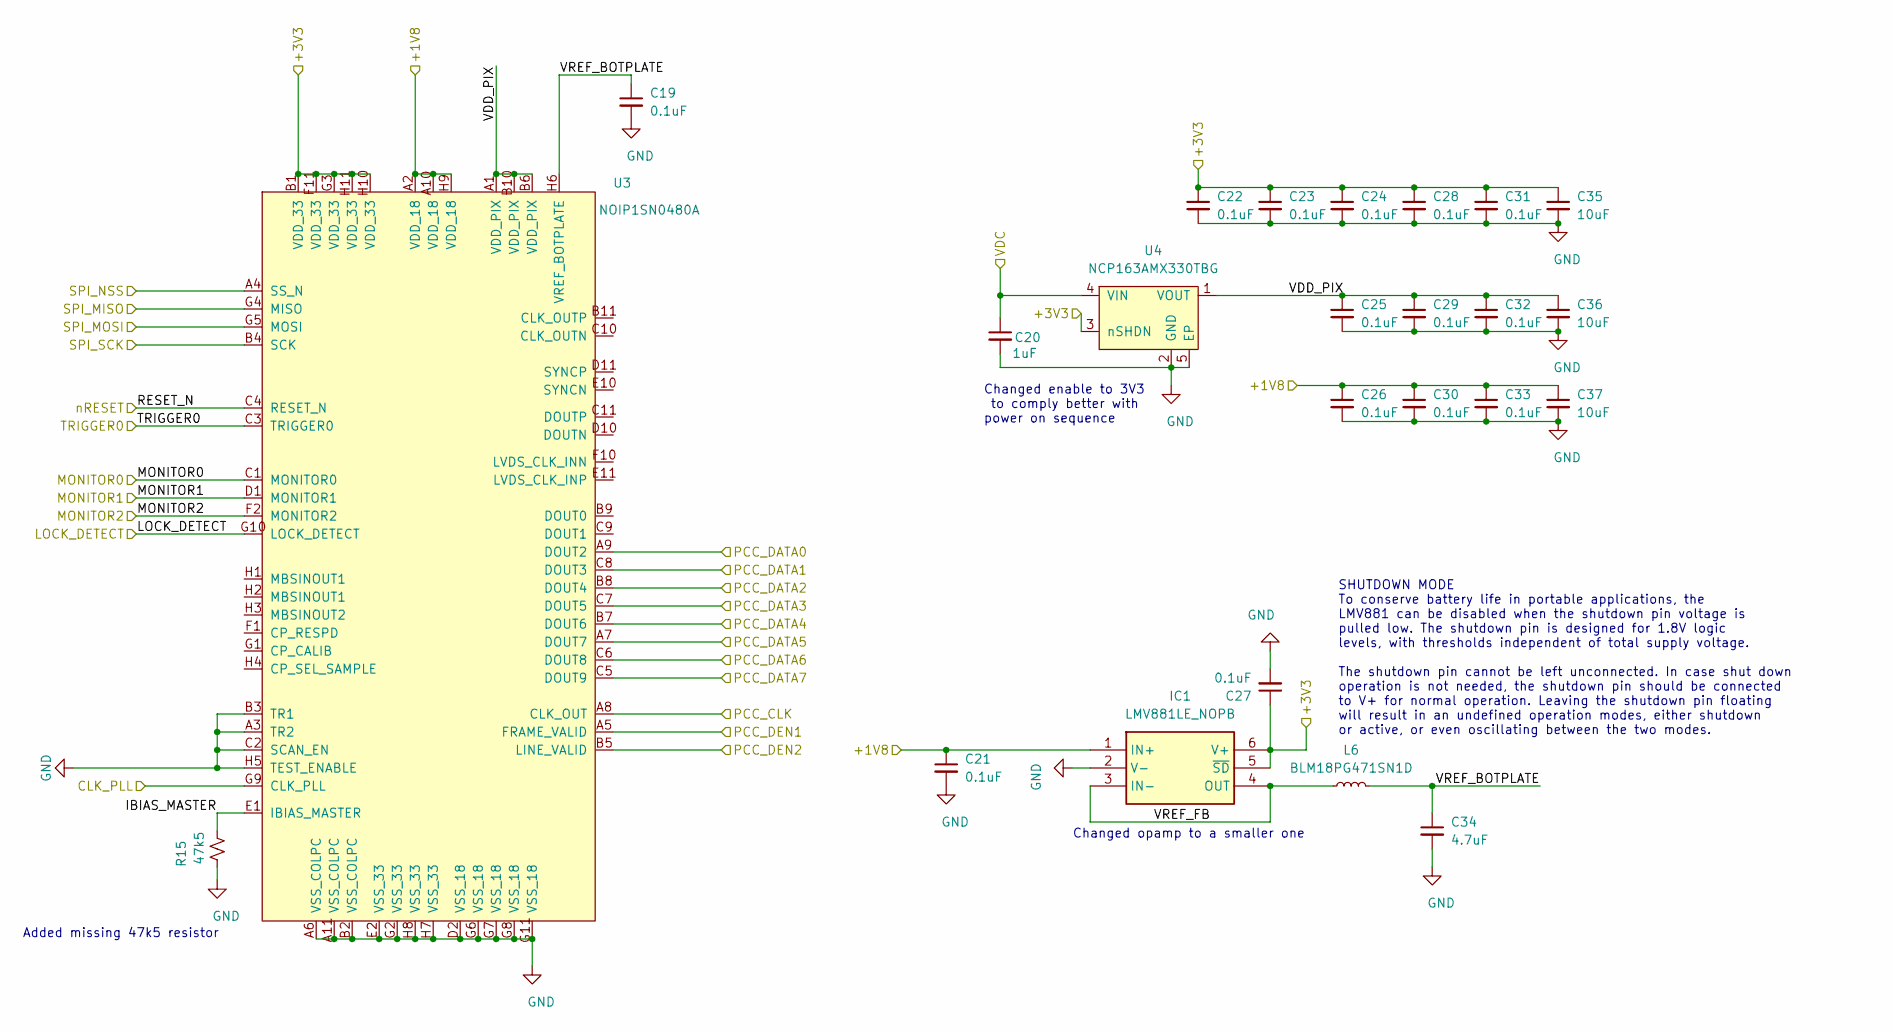
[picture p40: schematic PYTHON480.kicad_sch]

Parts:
C19, C21, C22, C23, C24, C25, C26, C27, C28, C29, C30, C31, C32, C33: 0.1uF; C_0201_0603Metric_L; Manufacturer_Part_Number GRM033R61E104KE14J
C20: 1uF; C_0201_0603Metric_L; Manufacturer_Part_Number GRM033R61A105ME15D
C34: 4.7uF; C_0201_0603Metric_L; Manufacturer_Part_Number GRM035R60J475ME15D
C35, C36, C37: 10uF; C_0402_1005Metric_L; Manufacturer_Part_Number GRM155R60J106ME15D
IC1: LMV881LE_NOPB; SON50P100X150X55-6N; Manufacturer_Part_Number LMV881LE/NOPB; Mouser Part Number 595-LMV881LE/NOPB
L6: BLM18PG471SN1D; L_0603_1608Metric_L; Manufacturer_Part_Number BLM18PG471SN1D
R15: 47k5; R_0201_0603Metric_ERJ_L; Manufacturer_Part_Number CRCW020147K5FNED
U3: NOIP1SN0480A; BGA88CP50_8X11_493X613X75B25; Manufacturer_Part_Number NOIP1SN0480A-STI1
U4: NCP163AMX330TBG; UQFN_MCP1711; Manufacturer_Part_Number NCP163AMX330TBG

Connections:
/+1V8: C21.1, C26.1, C30.1, C33.1, C37.1, IC1.1 (IN+), U3.A2 (VDD_18), U3.A10 (VDD_18), U3.H9 (VDD_18); also elsewhere on the board
/+3V3: C22.1, C23.1, C24.1, C27.1, C28.1, C31.1, C35.1, IC1.5 (~SD), IC1.6 (V+), U3.B1 (VDD_33), U3.F11 (VDD_33), U3.G3 (VDD_33), U3.H10 (VDD_33), U3.H11 (VDD_33), U4.3 (nSHDN); also elsewhere on the board
/MCU/CLK1_OUT: U3.G9 (CLK_PLL); also elsewhere on the board
/MCU/PCC_CLK: U3.A8 (CLK_OUT); also elsewhere on the board
/MCU/PCC_DATA0: U3.A9 (DOUT2); also elsewhere on the board
/MCU/PCC_DATA1: U3.C8 (DOUT3); also elsewhere on the board
/MCU/PCC_DATA2: U3.B8 (DOUT4); also elsewhere on the board
/MCU/PCC_DATA3: U3.C7 (DOUT5); also elsewhere on the board
/MCU/PCC_DATA4: U3.B7 (DOUT6); also elsewhere on the board
/MCU/PCC_DATA5: U3.A7 (DOUT7); also elsewhere on the board
/MCU/PCC_DATA6: U3.C6 (DOUT8); also elsewhere on the board
/MCU/PCC_DATA7: U3.C5 (DOUT9); also elsewhere on the board
/MCU/PCC_DEN1: U3.A5 (FRAME_VALID); also elsewhere on the board
/MCU/PCC_DEN2: U3.B5 (LINE_VALID); also elsewhere on the board
/MCU/SPI1_MISO: U3.G4 (MISO); also elsewhere on the board
/MCU/SPI1_MOSI: U3.G5 (MOSI); also elsewhere on the board
/MCU/SPI1_NSS: U3.A4 (SS_N); also elsewhere on the board
/MCU/SPI1_SCK: U3.B4 (SCK); also elsewhere on the board
/PYTHON480/IBIAS_MASTER: R15.1, U3.E1 (IBIAS_MASTER)
/PYTHON480/LOCK_DETECT: U3.G10 (LOCK_DETECT)
/PYTHON480/MONITOR0: U3.C1 (MONITOR0); also elsewhere on the board
/PYTHON480/MONITOR1: U3.D1 (MONITOR1)
/PYTHON480/MONITOR2: U3.F2 (MONITOR2)
/PYTHON480/RESET_N: U3.C4 (RESET_N); also elsewhere on the board
/PYTHON480/TRIGGER0: U3.C3 (TRIGGER0); also elsewhere on the board
/PYTHON480/VDD_PIX: C25.1, C29.1, C32.1, C36.1, U3.A1 (VDD_PIX), U3.B6 (VDD_PIX), U3.B10 (VDD_PIX), U4.1 (VOUT)
/PYTHON480/VREF_BOTPLATE: C19.1, C34.1, L6.2, U3.H6 (VREF_BOTPLATE)
/PYTHON480/VREF_FB: IC1.3 (IN-), IC1.4 (OUT), L6.1
/VOUT_PMU: C20.1, U4.4 (VIN); also elsewhere on the board
GND: C19.2, C20.2, C21.2, C22.2, C23.2, C24.2, C25.2, C26.2, C27.2, C28.2, C29.2, C30.2, C31.2, C32.2, C33.2, C34.2, C35.2, C36.2, C37.2, IC1.2 (V-), R15.2, U3.A3 (TR2), U3.A6 (VSS_COLPC), U3.A11 (VSS_COLPC), U3.B2 (VSS_COLPC), U3.B3 (TR1), U3.C2 (SCAN_EN), U3.D2 (VSS_18), U3.E2 (VSS_33), U3.G2 (VSS_33), U3.G6 (VSS_18), U3.G7 (VSS_18), U3.G8 (VSS_18), U3.G11 (VSS_18), U3.H5 (TEST_ENABLE), U3.H7 (VSS_33), U3.H8 (VSS_33), U4.2 (GND), U4.5 (EP); also elsewhere on the board

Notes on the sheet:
SHUTDOWN MODE To conserve battery life in portable applications, the LMV881 can be disabled when the shutdown pin voltage is pulled low. The shutdown pin is designed for 1.8V logic levels, with thresholds independent of total supply voltage. The shutdown pin cannot be left unconnected. In case shut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
Added missing 47k5 resistor
Changed enable to 3V3 to comply better with power on sequence
Changed opamp to a smaller one

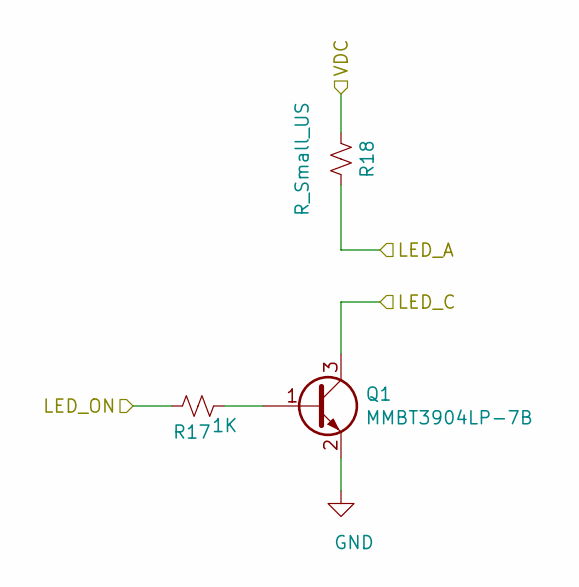
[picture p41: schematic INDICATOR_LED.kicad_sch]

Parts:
Q1: MMBT3904LP-7B; TRXDFN3_101X61X53L25X15N; Manufacturer_Part_Number MMBT3904LP-7B
R17: 1K; R_0201_0603Metric_ERJ_L; Manufacturer_Part_Number CRCW02011K00FKED
R18: R_Small_US; R_0201_0603Metric_ERJ_L

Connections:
/+3V3: R18.2; also elsewhere on the board
/INDICATOR_LED_DRIVER/LED_A: R18.1; also elsewhere on the board
/INDICATOR_LED_DRIVER/LED_C: Q1.3 (C); also elsewhere on the board
/IND_LED_CTRL: R17.2; also elsewhere on the board
GND: Q1.2 (E); also elsewhere on the board
unnamed: Q1.1 (B), R17.1

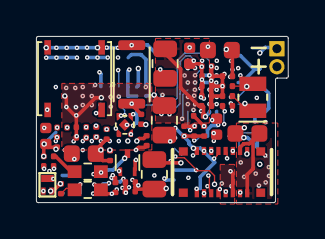
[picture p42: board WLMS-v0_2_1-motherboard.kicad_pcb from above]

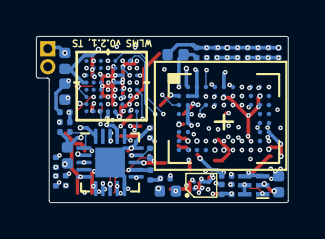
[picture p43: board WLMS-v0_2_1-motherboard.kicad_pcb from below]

Board: 8 copper layers, 14.0 x 9.2 mm, 80 parts (33 on the bottom side), 66 nets.

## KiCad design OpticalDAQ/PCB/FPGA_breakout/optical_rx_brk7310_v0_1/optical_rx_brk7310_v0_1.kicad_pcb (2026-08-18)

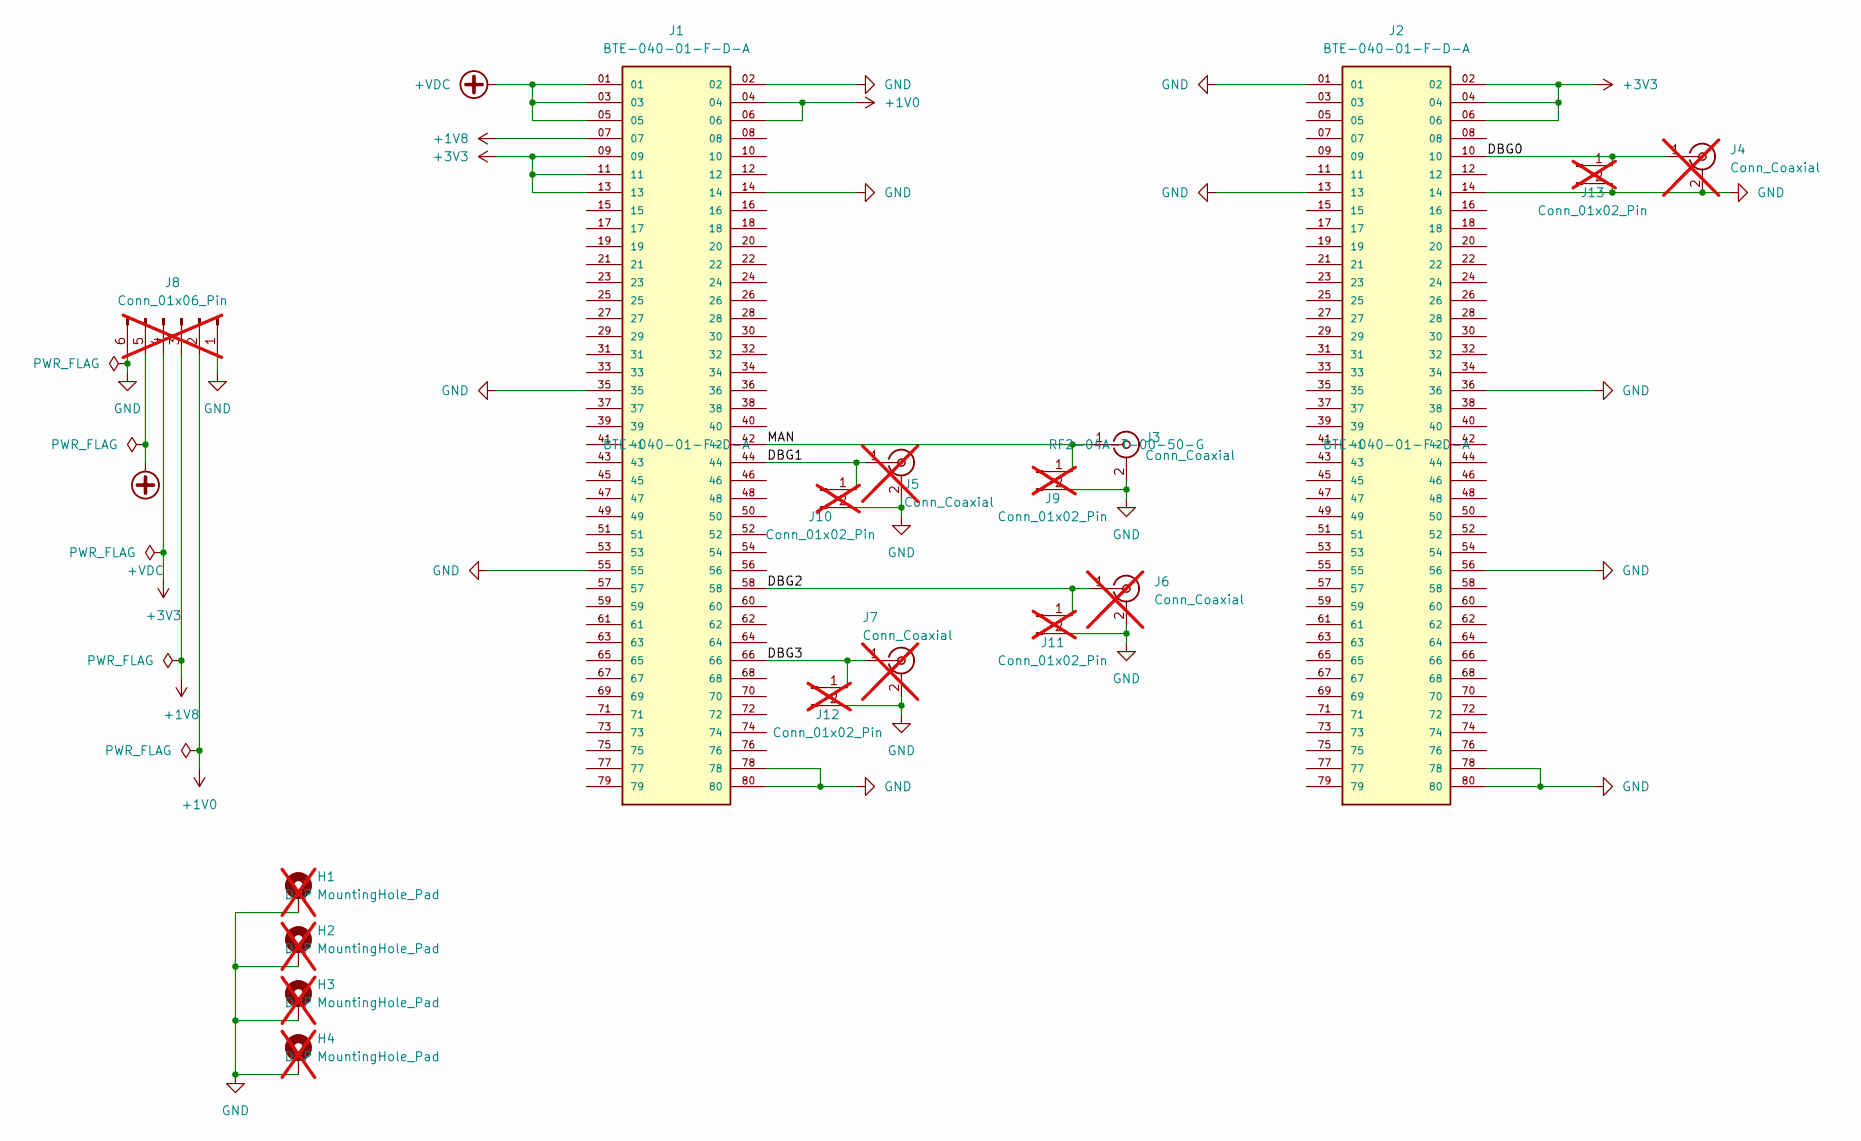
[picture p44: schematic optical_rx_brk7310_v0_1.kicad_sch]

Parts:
H1, H2, H3, H4: MountingHole_Pad; MountingHole_3.2mm_M3_Pad; MPN DNP; not fitted
J1, J2: BTE-040-01-F-D-A; SAMTEC_BTE-040-01-F-D-A; PARTREV R
J3: Conn_Coaxial; SMA_Amphenol_901-144_Vertical; MPN RF2-04A-T-00-50-G
J4, J5, J6, J7: Conn_Coaxial; SMA_Amphenol_901-144_Vertical; not fitted
J8: Conn_01x06_Pin; PinHeader_1x06_P2.54mm_Vertical; not fitted
J9, J10, J11, J12, J13: Conn_01x02_Pin; PinHeader_1x02_P2.54mm_Vertical; not fitted

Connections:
+1V0: J1.04, J1.06, J8.2
+1V8: J1.07, J8.3
+3V3: J1.09, J1.11, J1.13, J2.02, J2.04, J2.06, J8.4
+VDC: J1.01, J1.03, J1.05, J8.5
/DBG0: J2.10, J4.1 (In), J13.1
/DBG1: J1.44, J5.1 (In), J10.1
/DBG2: J1.58, J6.1 (In), J11.1
/DBG3: J1.66, J7.1 (In), J12.1
/MAN: J1.42, J3.1 (In), J9.1
GND: H1.1, H2.1, H3.1, H4.1, J1.02, J1.14, J1.35, J1.55, J1.78, J1.80, J2.01, J2.13, J2.14, J2.36, J2.56, J2.78, J2.80, J3.2 (Ext), J4.2 (Ext), J5.2 (Ext), J6.2 (Ext), J7.2 (Ext), J8.1, J8.6, J9.2, J10.2, J11.2, J12.2, J13.2

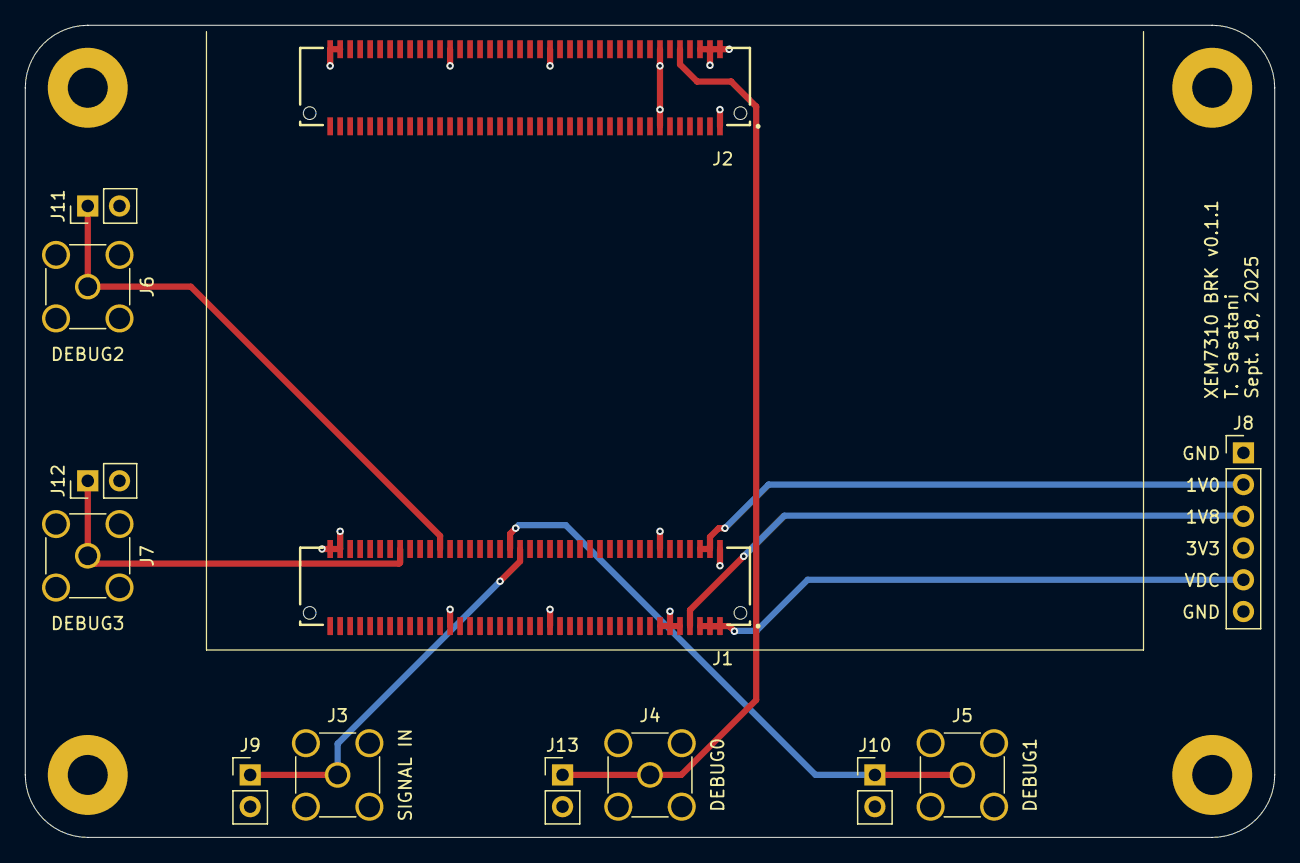
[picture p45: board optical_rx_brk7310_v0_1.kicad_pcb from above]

Board: 4 copper layers, 100.0 x 65.0 mm, 17 parts (0 on the bottom side), 10 nets.

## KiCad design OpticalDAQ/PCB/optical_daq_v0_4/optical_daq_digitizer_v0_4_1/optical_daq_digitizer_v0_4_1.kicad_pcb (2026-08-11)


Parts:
C1, C31: DNP; C_0603_1608Metric; not fitted
C2, C3: 0.1u; C_0603_1608Metric; MPN GCJ188R71E104KA12D
C32: 1000p; C_0603_1608Metric; MPN GRM1885C1H102JA01D
H1, H2, H3, H4: MountingHole_Pad; MountingHole_3.2mm_M3_Pad; not fitted
J1: SMA; SMA_Amphenol_901-144_Vertical; not fitted
J3, J8: SMA; SMA_Amphenol_901-144_Vertical; MPN RF2-04A-T-00-50-G
J4, J5, J6, J7, J9, J10, J11, J12, J14, J15: DNP; PinHeader_1x02_P2.54mm_Vertical; not fitted
J13: Screw_Terminal_01x02; TerminalBlock_TE_282834-2_1x02_P2.54mm_Horizontal; MPN 282834-2; not fitted
JP1, JP2: SolderJumper_2_Open; SolderJumper-2_P1.3mm_Open_RoundedPad1.0x1.5mm; not fitted
R1, R7, R21: DNP; R_0603_1608Metric; not fitted
R2: 47; R_0603_1608Metric; MPN ERJ-3EKF47R0V
R3: 1k; R_0603_1608Metric; MPN CRCW06031K00FKEA
R4: 0; R_0603_1608Metric; MPN CRCW06030000Z0EA
R5: 20; R_0603_1608Metric; MPN ERJ-3EKF20R0V
R6: 2k; R_0603_1608Metric; MPN CRCW06032K00FKEA
R8: 33.2k; R_0603_1608Metric; MPN ERJ-3EKF3322V
R9, R10: 10k; R_0603_1608Metric; MPN CR0603-FX-1002ELF
RV1: 3314J-1-502E; Potentiometer_Bourns_3314J_Vertical; MPN 3314J-1-502E
U1: SN74LV1T00DCKR; SOT-353_SC-70-5; MPN SN74LV1T00DCKR

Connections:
+3V3: C3.2, C31.2, J14.2, R9.1, U1.5 (VCC); also elsewhere on the board
+5V: J13.1; also elsewhere on the board
/digitalout: J8.1 (In), J9.2, R21.1, U1.4 (Y)
/negative peak detector/negative_peak: J11.1; also elsewhere on the board
/negative peak detector/signal_in: C2.1, J7.2, R1.1, R2.1; also elsewhere on the board
/output comparator/digital_out: R4.1; also elsewhere on the board
/output comparator/signal+: J15.1, JP1.1 (A), JP2.2 (B); also elsewhere on the board
/positive peak detector/positive_peak: J4.1; also elsewhere on the board
/positive_adj_ldo/R_SET: R8.2; also elsewhere on the board
/voltage_follower1/signal_out: J5.1, R3.2; also elsewhere on the board
/voltage_follower2/signal_out: C32.2, J12.1, R6.1, RV1.1; also elsewhere on the board
/voltage_follower3/signal_in: R9.2, R10.1; also elsewhere on the board
GND: C1.2, C3.1, C31.1, H1.1, H2.1, H3.1, H4.1, J1.2 (Ext), J3.2 (Ext), J4.2, J5.2, J6.1, J7.1, J8.2 (Ext), J9.1, J10.2, J11.2, J12.2, J13.2, J14.1, J15.2, R7.2, R8.1, R10.2, R21.2, U1.3 (GND); also elsewhere on the board
unnamed: C1.1, J1.1 (In), JP1.2 (B), R1.2
unnamed: C2.2, J3.1 (In), J6.2
unnamed: J10.1, R5.2, U1.1 (B), U1.2 (A)
unnamed: C32.1, JP2.1 (A), R3.1, R6.2, RV1.2
unnamed: R4.2, R5.1, R7.1
Vbias: R2.2; also elsewhere on the board

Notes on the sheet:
USE NAND (SN74LV1T00DCKR) instead of AND
signal biasing
threshold adjust R3:1k, R4:2k, Radj:MAX5k
power supply ports
mount hole
termination


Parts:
C28: DNP; C_0603_1608Metric; not fitted
C29: 2.2u; C_0603_1608Metric; MPN C1608X5R1C225K080AB
C30: 100p; C_0603_1608Metric; MPN C1608C0G1H101J080AA
R19: DNP; R_0603_1608Metric; not fitted
R20: 30k; R_0603_1608Metric; MPN ERJ-3EKF3002V
U8: LTC6752IMS8-2#TRPBF; MSOP-8_3x3mm_P0.65mm; MPN LTC6752IMS8-2#TRPBF

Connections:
+3V3: C28.2, C29.2, C30.2, U8.1 (VCC), U8.8 (VDD); also elsewhere on the board
/negative peak detector/signal_in: U8.3 (-); also elsewhere on the board
/output comparator/digital_out: R19.1, U8.7; also elsewhere on the board
/output comparator/signal+: R19.2, U8.2 (+); also elsewhere on the board
GND: C28.1, C29.1, C30.1, R20.1, U8.6 (VEE); also elsewhere on the board
unnamed: R20.2, U8.5 (~LE)

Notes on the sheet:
82k for 15 mV hysteresis 30k for 48 mV hysteresis USED THIS ONE in v02 board numbr 1+2


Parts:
C19: 1u; C_0603_1608Metric; MPN GRM188R61A105KA61D
C20: 0.1u; C_0603_1608Metric; MPN GCJ188R71E104KA12D
C21: 1000p; C_0603_1608Metric; MPN GRM1885C1H102JA01D
U5: LTC6228IS6#TRMPBF; TSOT-23-6; MPN LTC6228IS6#TRMPBF

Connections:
+3V3: C19.2, C20.2, C21.2, U5.5 (~SHDN), U5.6 (V+); also elsewhere on the board
/positive peak detector/positive_peak: U5.3 (+); also elsewhere on the board
/voltage_follower1/signal_out: U5.1, U5.4 (-); also elsewhere on the board
GND: C19.1, C20.1, C21.1, U5.2 (V-); also elsewhere on the board

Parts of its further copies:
C22, C25: 1u; C_0603_1608Metric; MPN GRM188R61A105KA61D
C23, C26: 0.1u; C_0603_1608Metric; MPN GCJ188R71E104KA12D
C24, C27: 1000p; C_0603_1608Metric; MPN GRM1885C1H102JA01D
U6, U7: LTC6228IS6#TRMPBF; TSOT-23-6; MPN LTC6228IS6#TRMPBF

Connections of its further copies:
+3V3: C22.2, C23.2, C24.2, C25.2, C26.2, C27.2, U6.5 (~SHDN), U6.6 (V+), U7.5 (~SHDN), U7.6 (V+); also elsewhere on the board
/negative peak detector/negative_peak: U7.3 (+); also elsewhere on the board
/voltage_follower2/signal_out: U7.1, U7.4 (-); also elsewhere on the board
/voltage_follower3/signal_in: U6.3 (+); also elsewhere on the board
GND: C22.1, C23.1, C24.1, C25.1, C26.1, C27.1, U6.2 (V-), U7.2 (V-); also elsewhere on the board
Vbias: U6.1, U6.4 (-); also elsewhere on the board


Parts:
C11: DNP; C_0603_1608Metric; not fitted
C12: 2.2u; C_0603_1608Metric; MPN C1608X5R1C225K080AB
C13: 100p; C_0603_1608Metric; MPN C1608C0G1H101J080AA
C14: 1000p; C_0603_1608Metric; MPN GRM1885C1H102JA01D
D2: PMEG2010AEJ; D_SOD-323F; MPN PMEG2010AEJ,115
R17: 100k; R_0603_1608Metric; MPN ERJ-3EKF1003V
U3: LTC6752IS5#TRMPBF; TSOT-23-5; MPN LTC6752IS5#TRMPBF

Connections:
+3V3: C11.2, C12.2, C13.2, U3.5 (VCC); also elsewhere on the board
/negative peak detector/signal_in: U3.3 (+); also elsewhere on the board
/positive peak detector/positive_peak: C14.1, D2.1 (K), R17.2, U3.4 (-); also elsewhere on the board
GND: C11.1, C12.1, C13.1, C14.2, R17.1, U3.2 (VEE); also elsewhere on the board
unnamed: D2.2 (A), U3.1


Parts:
C4: 10u/tant; CP_EIA-3216-10_Kemet-I; MPN TAJA106K010RNJ
C5, C9: 10u; C_1206_3216Metric; MPN GRM31CR71E106KA12L
C6: 4.7u; C_0603_1608Metric; MPN GRM188Z71A475ME15D
C7, C8: 1000p; C_0603_1608Metric; MPN GRM1885C1H102JA01D
C10: 0.47u; C_0603_1608Metric; MPN GRM188R71E474KA12D
D1: LED; LED_0603_1608Metric; MPN 150060RS75003
FB1: FerriteBead; L_0603_1608Metric; MPN BLM18AG102SN1D
Q1: 2N7002BK; SOT-23; MPN 2N7002BK,215
R11: 10k; R_0603_1608Metric; MPN CR0603-FX-1002ELF
R12: 200k; R_0603_1608Metric; MPN ERJ-3EKF2003V
R13: 470m; R_0603_1608Metric; MPN ERJ-3RQJR47V
R14: 453k; R_0603_1608Metric; MPN ERJ-3EKF4533V
R15: 300; R_0603_1608Metric; MPN ERJ-PA3F3000V
R16: 49.9k; R_0603_1608Metric; MPN ERA-3AED4992V
U2: LT3045xDD; DFN-10-1EP_3x3mm_P0.5mm_EP1.65x2.38mm; MPN LT3045EDD#PBF

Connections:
+3V3: C8.1, C9.1, R11.1, R12.1, R14.1, U2.9 (OUTS), U2.10 (OUT); also elsewhere on the board
+5V: FB1.1; also elsewhere on the board
/positive_adj_ldo/R_SET: C10.1, U2.7 (SET); also elsewhere on the board
GND: C4.2, C5.2, C6.2, C7.2, C8.2, C9.2, C10.2, Q1.2 (S), R15.2, R16.2, U2.8 (GND), U2.11 (GND); also elsewhere on the board
unnamed: D1.2 (A), R11.2
unnamed: D1.1 (K), Q1.3 (D)
unnamed: FB1.2, R13.1
unnamed: Q1.1 (G), R12.2, U2.4 (PG)
unnamed: C4.1, C5.1, C6.1, C7.1, R13.2, U2.1 (IN), U2.2 (IN), U2.3 (EN/UV)
unnamed: R15.1, U2.5 (ILIM)
unnamed: R14.2, R16.1, U2.6 (PGFB)

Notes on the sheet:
X7R or X5R Recommended: Murata GJ8 ESR < 20 mOhm, ESL < 2nH
PG threshold: 3 ~ 0.3 * (1 + 450k/49.9k)
Damping R is recommendend. R (0.1 to 0.5 Ohm)
Current limit: R_ILIM = 0 Ohm for no current limit
Output voltage: V_SET = I_SET * R_SET


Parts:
C15: DNP; C_0603_1608Metric; not fitted
C16: 2.2u; C_0603_1608Metric; MPN C1608X5R1C225K080AB
C17: 100p; C_0603_1608Metric; MPN C1608C0G1H101J080AA
C18: 1000p; C_0603_1608Metric; MPN GRM1885C1H102JA01D
D3: PMEG2010AEJ; D_SOD-323F; MPN PMEG2010AEJ,115
R18: 100k; R_0603_1608Metric; MPN ERJ-3EKF1003V
U4: LTC6752IS5#TRMPBF; TSOT-23-5; MPN LTC6752IS5#TRMPBF

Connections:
+3V3: C15.2, C16.2, C17.2, C18.2, R18.1, U4.5 (VCC); also elsewhere on the board
/negative peak detector/negative_peak: C18.1, D3.2 (A), R18.2, U4.4 (-); also elsewhere on the board
/negative peak detector/signal_in: U4.3 (+); also elsewhere on the board
GND: C15.1, C16.1, C17.1, U4.2 (VEE); also elsewhere on the board
unnamed: D3.1 (K), U4.1



Board: 4 copper layers, 60.0 x 70.0 mm, 87 parts (3 on the bottom side), 29 nets.

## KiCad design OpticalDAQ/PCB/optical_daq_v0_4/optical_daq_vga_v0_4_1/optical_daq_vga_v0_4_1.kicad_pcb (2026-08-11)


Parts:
C1, C3, C5, C9, C10, C16, C17: 1000p; C_0603_1608Metric; MPN GRM1885C1H102JA01D
C2, C4: 0.1u; C_0603_1608Metric; MPN GCJ188R71E104KA12D
C6, C13: 10u/tant; CP_EIA-3216-10_Kemet-I; MPN TAJA106K010RNJ
C7, C11, C14, C18: 10u; C_1206_3216Metric; MPN GRM31CR71E106KA12L
C8, C15, C19: 4.7u; C_0603_1608Metric; MPN GRM188Z71A475ME15D
C12: 0.47u; C_0603_1608Metric; MPN GRM188R71E474KA12D
D1, D2: LED; LED_0603_1608Metric; MPN 150060RS75003
FB1, FB2: FerriteBead; L_0603_1608Metric; MPN BLM18KG121TN1D
H1, H2, H3, H4: MountingHole_Pad; MountingHole_3.2mm_M3_DIN965_Pad
J1, J5, J6, J7, J8, J12, J13, J14, J20, J21: DNP; PinHeader_1x02_P2.54mm_Vertical; not fitted
J2, J3, J15, J17, J18, J19: DNP; SMA_Amphenol_901-144_Vertical; not fitted
J4, J9, J10, J11: Conn_Coaxial; SMA_Amphenol_901-144_Vertical; MPN RF2-04A-T-00-50-G
J16: Screw_Terminal_01x04; TerminalBlock_TE_282834-4_1x04_P2.54mm_Horizontal; MPN 282834-4; not fitted
JP1, JP2, JP3: SolderJumper_2_Bridged; SolderJumper-2_P1.3mm_Bridged_RoundedPad1.0x1.5mm
JP4, JP5: SolderJumper_3_Open; SolderJumper-3_P1.3mm_Open_RoundedPad1.0x1.5mm
R1: 121k; R_0603_1608Metric; MPN ERJ-3EKF1213V
R2, R3: 154k; R_0603_1608Metric; MPN ERJ-3EKF1543V
R4, R6, R8, R10, R14, R16: DNP; R_0603_1608Metric; not fitted
R5: 30.1k; R_0603_1608Metric; MPN ERJ-3RBD3012V
R7, R11, R12, R13: 0; R_0603_1608Metric; MPN CRCW06030000Z0EA
R9, R15: 1k; R_0603_1608Metric; MPN CRCW06031K00FKEA
R17, R18: 49.9; R_0603_1608Metric; MPN ERJ-3EKF49R9V
R20, R27: 10k; R_0603_1608Metric; MPN CR0603-FX-1002ELF
R21, R28: 470m; R_0603_1608Metric; MPN ERJ-3RQJR47V
R22, R29: 453k; R_0603_1608Metric; MPN ERJ-3EKF4533V
R23: 300; R_0603_1608Metric; MPN ERJ-PA3F3000V
R24, R31: 33.2k; R_0603_1608Metric; MPN ERJ-3EKF3322V
R25, R32: 49.9k; R_0603_1608Metric; MPN CRCW060349K9FKEA
R30: 7.5k; R_0603_1608Metric; MPN ERJ-3EKF7501V
RV1, RV2: 3314G-1-104E; Potentiometer_Bourns_3314G_Vertical; MPN 3314G-2-104E
TP3, TP4, TP5, TP6, TP7: DNP; TestPoint_Keystone_5000-5004_Miniature; not fitted
U1: AD8264; HVQFN-40-1EP_6x6mm_P0.5mm_EP4.1x4.1mm; MPN AD8264ACPZ
U2: LT3045xDD; DFN-10-1EP_3x3mm_P0.5mm_EP1.65x2.38mm; MPN LT3045EDD#PBF
U3: LT3094xDD; DFN-12-1EP_3x3mm_P0.45mm_EP1.65x2.38mm_ThermalVias; MPN LT3094EDD#TRPBF

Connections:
+3V3: C10.1, C11.1, R1.1, R2.1, R3.1, R20.1, R22.1, TP6.1, U1.16 (VPOS), U1.35 (VPOS), U2.9 (OUTS), U2.10 (OUT)
+5V: FB1.1, J15.1 (In), J16.4
-3V3: C17.1, C18.1, D2.1 (K), R29.1, TP7.1, U1.17 (VNEG), U1.34 (VNEG), U3.10 (OUTS), U3.11 (OUT), U3.12 (OUT)
-5V: FB2.1, J16.1, J17.1 (In)
GND: C1.1, C3.1, C5.1, C6.2, C7.2, C8.2, C9.2, C10.2, C11.2, C12.2, C13.1, C14.2, C15.2, C16.2, C17.2, C18.2, C19.2, D1.1 (K), H1.1, H2.1, H3.1, H4.1, J1.2, J2.2 (Ext), J3.2 (Ext), J4.2 (Ext), J5.2, J6.2, J7.2, J8.2, J9.2 (Ext), J10.2 (Ext), J11.2 (Ext), J12.2, J13.2, J14.2, J15.2 (Ext), J16.2, J16.3, J17.2 (Ext), J18.2 (Ext), J19.2 (Ext), J20.2, J21.2, JP1.1 (A), JP2.1 (A), JP3.1 (A), R5.2, R8.2, R9.2, R10.2, R14.2, R15.2, R16.2, R17.1, R18.1, R23.2, R24.2, R25.2, R27.1, R30.2, R31.2, R32.2, RV1.3, RV2.3, U1.12 (COMM), U1.39 (COMM), U1.41 (COMM), U2.8 (GND), U2.11 (GND), U3.9 (GND)
unnamed: C2.2, R7.1, R9.1
unnamed: C4.2, R12.1, R15.1
unnamed: D1.2 (A), R20.2
unnamed: D2.2 (A), R27.2
unnamed: FB1.2, R21.1
unnamed: FB2.2, R28.1
unnamed: J1.1, J2.1 (In), R4.2
unnamed: J3.1 (In), J5.1, R6.2
unnamed: C2.1, J4.1 (In), J7.1, R8.1
unnamed: J6.1, J9.1 (In), R11.2
unnamed: J8.1, R7.2, R10.1, U1.40 (IPP1)
unnamed: C4.1, J10.1 (In), J12.1, R14.1
unnamed: J11.1 (In), J14.1, R13.2
unnamed: J13.1, R12.2, R16.1, U1.5 (IPP2)
unnamed: J18.1 (In), J20.1, JP4.3 (B)
unnamed: J19.1 (In), J21.1, JP5.3 (B)
unnamed: JP1.2 (B), TP3.1, U1.15 (VOCM)
unnamed: JP2.2 (B), TP4.1, U1.33 (OFS1)
unnamed: JP3.2 (B), TP5.1, U1.32 (OFS2)
unnamed: JP4.1 (A), RV2.2
unnamed: C3.2, JP4.2 (C), U1.38 (GNH1)
unnamed: JP5.1 (A), RV1.2
unnamed: C5.2, JP5.2 (C), U1.37 (GNH2)
unnamed: R2.2, RV1.1
unnamed: R3.2, RV2.1
unnamed: C1.2, R1.2, R5.1, U1.36 (GNLO)
unnamed: R17.2, U1.6 (IPP3)
unnamed: R18.2, U1.11 (IPP4)
unnamed: R4.1, U1.2 (OPP1)
unnamed: R6.1, U1.3 (OPP2)
unnamed: R11.1, U1.31 (VGA1)
unnamed: R13.1, U1.26 (VGA2)
unnamed: C6.1, C7.1, C8.1, C9.1, R21.2, U2.1 (IN), U2.2 (IN), U2.3 (EN/UV)
unnamed: R23.1, U2.5 (ILIM)
unnamed: R22.2, R25.1, U2.6 (PGFB)
unnamed: C12.1, R24.1, U2.7 (SET)
unnamed: C13.2, C14.1, C15.1, C16.1, R28.2, U3.1 (IN), U3.2 (IN), U3.3 (EN/UV), U3.13 (IN)
unnamed: R30.1, U3.6 (ILIM)
unnamed: R29.2, R32.1, U3.5 (PGFB)
unnamed: C19.1, R31.1, U3.8 (SET)

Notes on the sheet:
PG threshold: -3 ~ -0.3 * (1 + 450k/49.9k)
PG threshold: 3 ~ 0.3 * (1 + 450k/49.9k)
OFSx is only for differential output
Current limit: R_ILIM = 0 Ohm for no current limit
X7R or X5R Recommended: Murata GJ8 ESR < 20 mOhm, ESL < 2nH
0<GNHx<1.3V
Output voltage: V_SET = I_SET * R_SET
V_GAIN = GNHx = GNLO For 3.3 V supply: |V_GNLO| < 1.2 and |V_GAIN|<0.65 Design for full dynamic range with V_GNLO = 0.65
Floating in the same way as eval board
R_ILIM = 0 Ohm for no current limit
Damping R is recommendend. R (0.1 to 0.5 Ohm)



Board: 4 copper layers, 80.0 x 70.0 mm, 93 parts (5 on the bottom side), 45 nets.

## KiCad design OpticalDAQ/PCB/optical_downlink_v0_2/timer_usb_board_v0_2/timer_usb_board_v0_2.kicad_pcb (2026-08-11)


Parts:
C1, C3, C4, C7, C9: 0.1u; C_0603_1608Metric
C2: 10u; CP_EIA-1608-08_AVX-J
C5: 10u; C_0603_1608Metric
C6: 10u; CP_Elec_4x5.4
C8: C_osc; C_0603_1608Metric
D1: LED_GREEN; LED_0603_1608Metric
D2: LED_RED; LED_0603_1608Metric
D3, D4, D5: ESD9B5.0ST5G; D_SOD-923
F1: Polyfuse; Fuse_1206_3216Metric
H1, H2, H3, H4: MountingHole; MountingHole_3.2mm_M3
IC1: SN74LV1T86DCKRG4; SOT65P210X110-5N; Manufacturer_Part_Number SN74LV1T86DCKRG4; Mouser Part Number 595-SN74LV1T86DCKRG4
J1: USB_B_Micro; USB_Micro-B_Amphenol_10118194-0001LF_Horizontal
J4, J5, J7: Conn_Coaxial; SMA_Amphenol_901-143_Horizontal
J6: Conn_01x03_Pin; PinHeader_1x03_P2.54mm_Vertical
JP1: SolderJumper_3_Bridged12; SolderJumper-3_P1.3mm_Bridged12_RoundedPad1.0x1.5mm
R1, R2: 470; R_0603_1608Metric
R3: 2k; R_0603_1608Metric
R4: 4.7k; R_0603_1608Metric
R5: 1k; R_0603_1608Metric
R6: R_osc; R_0603_1608Metric
TP1, TP2: TestPoint; TestPoint_Pad_D2.0mm
U1: FT232RL; SSOP-28_5.3x10.2mm_P0.65mm
U2: LMC555xM; SOIC-8_3.9x4.9mm_P1.27mm

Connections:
3V3: C4.1, C7.1, C9.1, IC1.5 (VCC), R5.2, U1.4 (VCCIO), U1.17 (3V3OUT), U2.4 (R), U2.8 (VCC)
GND: C1.2, C2.2, C3.2, C4.2, C5.2, C6.2, C7.2, C8.2, C9.2, D3.1 (A1), D4.1 (A1), D5.1 (A1), IC1.3 (GND), J1.5 (GND), J4.2 (Ext), J5.2 (Ext), J7.2 (Ext), R1.2, U1.7 (GND), U1.18 (GND), U1.21 (GND), U1.25 (AGND), U1.26 (TEST), U2.1 (GND)
unnamed: D1.2 (A), R3.2
unnamed: D1.1 (K), U1.23 (CBUS0)
unnamed: D2.2 (A), R4.2
unnamed: D2.1 (K), U1.22 (CBUS1)
unnamed: D3.2 (A2), F1.1, J1.1 (VBUS)
unnamed: D4.2 (A2), J1.3 (D+), U1.15 (USBD+)
unnamed: D5.2 (A2), J1.2 (D-), U1.16 (USBD-)
unnamed: IC1.4 (Y), J5.1 (In)
unnamed: C3.1, J1.6 (Shield), R1.1
unnamed: JP1.1 (A), R6.2, U2.3 (Q)
unnamed: JP1.3 (B), R5.1, U2.7 (DIS)
unnamed: TP2.1, U1.5 (RXD)
unnamed: R2.2, U1.19 (~RESET)
unnamed: C8.1, R6.1, U2.2 (TR), U2.6 (THR)
SG_CLK: J6.1, J7.1 (In)
TIMER_CLK: J6.3, JP1.2 (C)
UART_TX: IC1.1 (A), TP1.1, U1.1 (TXD)
VCC: C1.1, C2.1, C5.1, C6.1, F1.2, J4.1 (In), R2.1, R3.1, R4.1, U1.20 (VCC)
f_c: IC1.2 (B), J6.2

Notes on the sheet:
Carrier select


Board: 4 copper layers, 40.0 x 40.0 mm, 36 parts (1 on the bottom side), 21 nets.

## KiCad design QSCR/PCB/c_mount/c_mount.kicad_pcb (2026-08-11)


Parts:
J1, J2, J3, J4, J5, J6: Conn_Coaxial; SMA_Amphenol_901-144_Vertical

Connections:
/in_pad: J1.1 (In), J2.1 (In), J3.1 (In), J4.1 (In), J5.1 (In), J6.1 (In)
/out_pad: J1.2 (Ext), J2.2 (Ext), J3.2 (Ext), J4.2 (Ext), J5.2 (Ext), J6.2 (Ext)

Board: 2 copper layers, 6 parts (0 on the bottom side), 2 nets, no tracks yet.

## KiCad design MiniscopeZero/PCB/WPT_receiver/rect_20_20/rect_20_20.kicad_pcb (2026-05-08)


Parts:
C1, C2, C3, C4: C; C_0402_1005Metric
NT1, NT2: NetTie_2; NetTie-2_SMD_Pad0.5mm
TP1, TP2: TestPoint; TestPoint_THTPad_D1.0mm_Drill0.5mm

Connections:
/coil: NT1.1, NT2.2
unnamed: C1.1, C2.1, C3.1, C4.1, NT1.2
unnamed: C1.2, C2.2, NT2.1, TP2.1
unnamed: C3.2, C4.2, TP1.1



Board: 6 copper layers, 20.0 x 20.0 mm, 8 parts (5 on the bottom side), 4 nets.

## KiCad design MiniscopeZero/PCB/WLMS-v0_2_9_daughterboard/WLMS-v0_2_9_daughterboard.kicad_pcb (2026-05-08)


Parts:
D1: LED; LED_0603_1608Metric; not fitted
D2: LXZ1-PB01; LED_LXZ1_PR01_L; Manufacturer_Part_Number LXZ1-PB01
FB1: FerriteBead (0 Ohm); L_0201_0603Metric; Manufacturer_Part_Number ERJ-1GN0R00C
J1: 505551-1620; 5055511620; Manufacturer_Part_Number 505551-1620
J3, J4, J5, J6: Conn_01x02_Pin; PinHeader_1x02_P1.00mm_Vertical; not fitted
J7: Conn_02x06_Odd_Even; PinHeader_2x06_P2.54mm_Vertical

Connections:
+1V8: J1.9, J7.7
+3V3: J1.11, J7.6; also elsewhere on the board
/ADC_WPT: J1.12; also elsewhere on the board
/DATALED_A: D1.2 (A); also elsewhere on the board
/DATALED_C: D1.1 (K); also elsewhere on the board
/EXLED_A: FB1.1, J1.13
/EXLED_C: D2.A, FB1.2
/MANCHESTER_OUT: J6.1, J7.2; also elsewhere on the board
/MCU_nRESET: J1.1, J7.3
/RF1A: J3.2; also elsewhere on the board
/RF1B: J3.1; also elsewhere on the board
/RF2A: J4.2; also elsewhere on the board
/RF2B: J4.1; also elsewhere on the board
/RF3A: J5.2; also elsewhere on the board
/RF3B: J5.1; also elsewhere on the board
/SPI_DATA_CLK: J1.10, J7.11; also elsewhere on the board
/SPI_DATA_MOSI: J1.8, J7.10; also elsewhere on the board
/SWCLK: J1.5, J7.5
/SWDIO: J1.3, J7.4
/UART_RX: J1.6
/UART_TX: J1.4
/VPREREG: J1.14, J1.15, J7.9; also elsewhere on the board
/VRECT: J7.8; also elsewhere on the board
GND: D2.C, J1.2, J1.7, J1.16, J6.2, J7.1, J7.12; also elsewhere on the board

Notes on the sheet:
Cuttable interface
Wired monitoring
Wireless Miniscope v0.2 motherboard Interfaces: * Battery 2 pin connector * Half-pitch (1.27 mm) pin socket * 16 pin board-to-board connector * +1V8 bus * +3V3 bus * GND (3 pin) * Wireless power Vin (2 pin), ADC (1 pin) * SPI-based data transmitter (2 pin) * UART (2 pin) * SWD (3 pin) * Excitation 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


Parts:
C1: 1000p; C_0201_0603Metric_L; Manufacturer_Part_Number CGA1A2X7R1E102K030BA
C2: 0.1u; C_0201_0603Metric_L; Manufacturer_Part_Number C0603X5R1C104K030BC
D3, D6, D10, D13: PMEG3002EEFZ; Manufacturer_Part_Number PMEG3002EEFZ

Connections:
/RF2A: D3.2 (A), D10.1 (K); also elsewhere on the board
/RF2B: D6.2 (A), D13.1 (K); also elsewhere on the board
/VRECT: C1.1, C2.1, D3.1 (K), D6.1 (K); also elsewhere on the board
GND: C1.2, C2.2, D10.2 (A), D13.2 (A); also elsewhere on the board

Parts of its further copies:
C7, C9: 1000p; C_0201_0603Metric_L; Manufacturer_Part_Number CGA1A2X7R1E102K030BA
C8, C10: 0.1u; C_0201_0603Metric_L; Manufacturer_Part_Number C0603X5R1C104K030BC
D4, D5, D8, D9, D11, D12, D14, D15: PMEG3002EEFZ; Manufacturer_Part_Number PMEG3002EEFZ

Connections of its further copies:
/RF1A: D4.2 (A), D11.1 (K); also elsewhere on the board
/RF1B: D8.2 (A), D14.1 (K); also elsewhere on the board
/RF3A: D5.2 (A), D12.1 (K); also elsewhere on the board
/RF3B: D9.2 (A), D15.1 (K); also elsewhere on the board
/VRECT: C7.1, C8.1, C9.1, C10.1, D4.1 (K), D5.1 (K), D8.1 (K), D9.1 (K); also elsewhere on the board
GND: C7.2, C8.2, C9.2, C10.2, D11.2 (A), D12.2 (A), D14.2 (A), D15.2 (A); also elsewhere on the board

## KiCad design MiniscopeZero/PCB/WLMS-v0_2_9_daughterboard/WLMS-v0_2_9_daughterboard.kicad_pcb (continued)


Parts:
C3, C6: 0.1u; C_0201_0603Metric_L; Manufacturer_Part_Number C0603X5R1C104K030BC
C4: 1u; C_0201_0603Metric_L; Manufacturer_Part_Number GRM033R61C105ME15D
C5: 10u; C_0402_1005Metric_L; Manufacturer_Part_Number GRM155R61A106ME11D
D7: BZX884B7V5; BZX884B7V5LHG308; Manufacturer_Part_Number BZX884-B7V5,315
IC1: LDFMPVR; Manufacturer_Part_Number LDFMPVR
R1: 9.1k; R_0201_0603Metric_ERJ_L; Manufacturer_Part_Number ERJ-1GNF9101C
R2: 1k; R_0201_0603Metric_ERJ_L; Manufacturer_Part_Number ERJ-1GJF1001C
R3: 150k; R_0201_0603Metric_ERJ_L; Manufacturer_Part_Number ERJ-1GJF1503C
R4: 30k; R_0201_0603Metric_ERJ_L; Manufacturer_Part_Number ERJ-1GNF3002C

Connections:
/ADC_WPT: R1.2, R2.1; also elsewhere on the board
/VPREREG: C6.1, IC1.1 (VOUT), R3.1; also elsewhere on the board
/VRECT: C3.1, C4.1, C5.1, D7.1 (K), IC1.5 (EN), IC1.6 (VIN), R1.1; also elsewhere on the board
/pre_regulator/PREREG_FB: IC1.2 (ADJ/NC), R3.2, R4.1
GND: C3.2, C4.2, C5.2, C6.2, D7.2 (A), IC1.4 (GND_1), IC1.7 (GND_2), R2.2, R4.2; also elsewhere on the board

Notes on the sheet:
R11 = 150k R12 = 30 k


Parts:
C11, C13: 0.1u; C_0201_0603Metric_L; Manufacturer_Part_Number C0603X5R1C104K030BC
C12: 1000p; C_0201_0603Metric_L; Manufacturer_Part_Number CGA1A2X7R1E102K030BA
IC2: 74LV1T86GXH; Texas_X2SON-5_0.8x0.8mm_P0.48mm; Manufacturer_Part_Number 74LV1T86GXH
Q1: EPC2038; Manufacturer_Part_Number EPC2038
R5: R; R_0402_1005Metric_ERJ_L; not fitted

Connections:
+3V3: C11.1, C12.1, C13.1, IC2.5 (VCC), R5.1; also elsewhere on the board
/DATALED_A: R5.2; also elsewhere on the board
/DATALED_C: Q1.3 (D); also elsewhere on the board
/MANCHESTER_OUT: IC2.4, Q1.1 (G); also elsewhere on the board
/SPI_DATA_CLK: IC2.2; also elsewhere on the board
/SPI_DATA_MOSI: IC2.1; also elsewhere on the board
GND: C11.2, C12.2, C13.2, IC2.3 (GND), Q1.2 (S1), Q1.4 (S2); also elsewhere on the board

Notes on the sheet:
Does XOR and level shift
Could be better to add more capacitance for slower speed



Board: 4 copper layers, 27.3 x 31.8 mm, 43 parts (2 on the bottom side), 23 nets.

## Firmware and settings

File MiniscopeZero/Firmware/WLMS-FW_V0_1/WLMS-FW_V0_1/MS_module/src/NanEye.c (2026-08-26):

// Daniel NanEye.c code is copied from the NanEye SAME70 code
// and has not been properly ported from SAME70 to this SAMD framework

#include "MS_config.h"
#include "MS_definitions.h"


#ifdef NANEYE_ENABLE
#include "NanEye.h"
// send data
void NanEyeInit(void)
{
	// Let's start naneye communication. To do this we will finish setting up the interface mode stuff and then turn on the DMAs
	naneye_new_reg_val_received = 1;
	
	naneyec_reg_val[0] = NANEYE_REG0_DEFAULT_VALUE | 0b1100; // Sets offset ramp to recommended 2.2V value
	naneyec_reg_val[0] = naneyec_reg_val[0] | 0b11; // Sets output current to max (might only effect LVDS mode)
	// sets naneye register
	// |= sets particular value to 1
	// &= with a ~ means and not, sets value to 0
	naneyec_reg_val[1] = NANEYE_REG1_DEFAULT_VALUE;
	naneyec_reg_val[1] |= (1<<10); // Increase 2x bias current, reduces settling time for high speed apps (not sure what this does)
	naneyec_reg_val[1] &= ~(1<<9); // Sets CDS gain to recommended value of 1.3 (turns a 1--> 0, which sets CDS gain to 1.3)
	naneyec_reg_val[1] &= ~(1<<8); // Sets mode to SEIM
	naneyec_reg_val[1] = (naneyec_reg_val[1] & (0b1111111111001111)) | (0b10 << 4); // Sets vref to recommended value of 2.1V
	naneyec_reg_val[1] = (naneyec_reg_val[1] & (0b1111111111110011)) | (0b01 << 2); // Sets CVC current to recommended value
	naneyec_reg_val[1] &= ~(1<<1); // Turns off idle mode
	
	interface_buffer_reg_set(naneyec_reg_val[0],naneyec_reg_val[1]);
	
	for (int i = 0; i<INTERFACE_MODE_SIZE; i++)
	{
		SERCOM4->SPI.DATA.reg = spi_interface_mode_tx_buffer[i];
	}
	//	SERCOM4->SPI.DATA.reg = naneyec_reg_val[1];
}
void startRecordingNE()
{
	writeFrameNum=0;
	writeBufferCount=0;
	droppedBufferCount= 0;
	droppedFrameCount = 0;
	framesToDrop = 0;
	
	deviceState &= ~(DEVICE_STATE_IDLE);
	deviceState &= ~(DEVICE_STATE_START_RECORDING);
	deviceState |= DEVICE_STATE_START_RECORDING_WAITING;
	
	
}

void stopRecordingNE()
{
	deviceState &= ~(DEVICE_STATE_STOP_RECORDING);
	deviceState &= ~(DEVICE_STATE_RECORDING);
	deviceState |= DEVICE_STATE_IDLE;
	setConfigBlockProp(CONFIG_BLOCK_NUM_BUFFERS_RECORDED_POS, writeBufferCount);
	setConfigBlockProp(CONFIG_BLOCK_NUM_BUFFERS_DROPPED_POS, droppedBufferCount);
}

#endif // NANEYE_ENABLE


// Below is Daniel's original NE code for SAME70 
#if 0
volatile uint32_t state = STATE_IDLE; // holds the current state of the SPI Naneye state machine

volatile uint32_t ms_ticks = 0; // Should count up in 1 ms increments
volatile uint32_t tick_factor = 1000; // Used to configure SysTick to interrupt at a specific interval

volatile uint32_t us_ticks = 0; // Should count up in 1 ms increments
volatile uint32_t us_tick_factor = 1000000; // Used to configure SysTick to interrupt at a specific interval

volatile uint32_t spi_dma_trash[2]; // Used for tx and rx in DMA when we don't need to save the data

volatile uint8_t spi_interface_mode_tx_buffer[INTERFACE_MODE_SIZE]; // Used to tx during interface mode
volatile uint8_t spi_initial_interface_mode_tx_buffer[INITIAL_INTERFACE_MODE_SIZE]; // Used to tx during interface mode

volatile uint8_t spi_readout_mode_rx_buffer[BUFFER_FRAME_SIZE][READOUT_MODE_SIZE];

// static xdmac_channel_config_t xdmac_cfg[8]; //XDMAC channel configuration.

volatile uint32_t spi_buffer_write_index = 0;

volatile uint8_t naneye_new_reg_val_received = 0;
volatile uint16_t naneyec_reg_val[2];

volatile bool frame_requested = false;
volatile bool debug_mode = false;

volatile uint32_t clk_freq;
// ------------------------------------------
void NanEyeRUN (void); // DANIEL Added the main loop function here

// -------------- Functions -----------------
void systick_init(void); // DANIEL Probably dont need this

void spi_init(void); // DANIEL Probably dont need this
void spi_xdmac_configure(Spi *const pspi); // DANIEL Probably dont need this
void spi_disable_xdmac(void); 
void spi_enable_xdmac(void); 

void interface_buffer_init(void);
void initial_interface_buffer_init(void);
void interface_buffer_reg_set(uint32_t, uint32_t);
void interface_buffer_reg_clear(void);

void spi_config_interface_mode(void); // need to switch polarity and not tristate MOSI
void spi_config_readout_mode(void);   // need to switch polarity and tristate MOSI
void spi_config_initial_interface_mode(void); // HS added for initializing IIM (initial interface mode)
void uart_handle_input(void);  // DANIEL Probably dont need this
// ------------------------------------------

void interface_buffer_init(void) {
	// Fill interface tx buffer with all 1's
	for (uint32_t i = 0; i < INTERFACE_MODE_SIZE; i++)
	spi_interface_mode_tx_buffer[i] = 0xFF;
}
void initial_interface_buffer_init(void) {
	// Fill interface tx buffer with all 0's
	for (uint32_t i = 0; i < INITIAL_INTERFACE_MODE_SIZE; i++)
	spi_interface_mode_tx_buffer[i] = 0x00;
}
void interface_buffer_reg_set(uint32_t reg0, uint32_t reg1) {
	// Cannot update regs in the first SPI clock of interface mode so we will start in the second byte location
	
	// For reg0
	spi_interface_mode_tx_buffer[1] = 0b10010000 | ((reg0 >> 15) & 0x01);
	spi_interface_mode_tx_buffer[2] = ((reg0 >> 7) & 0xFF);
	spi_interface_mode_tx_buffer[3] = ((reg0 << 1) & 0xFF);
	
	// For reg1
	// Lets give a 3 byte gap between writing the 2 registers
	spi_interface_mode_tx_buffer[7] = 0b10010010 | ((reg1 >> 15) & 0x01);
	spi_interface_mode_tx_buffer[8] = ((reg1 >> 7) & 0xFF);
	spi_interface_mode_tx_buffer[9] = ((reg1 << 1) & 0xFF);
}

void interface_buffer_reg_clear(void) {
	for (uint8_t i = 1; i < 10; i++)
	spi_initial_interface_mode_tx_buffer[i] = 0xFF;
}
// instead of using atmel start, this is written from scratch
// Daniel original NE code, configuration of MISO/MOSI pins, might be redundant
// this might be included in atmel_start_pins.h
// also I have some SPI initialization stuff at the end of this document

void spi_init(void) {
		// DANIEL THIS SHOULD BE IOPORT FROM THE atmel_start_pin.h or configuration, SEE BELOW 3 lines
// 	#define PB13 GPIO(GPIO_PORTB, 13) // DANIEL SCK
// 	#define PB14 GPIO(GPIO_PORTB, 14) // DANIEL MISO
// 	#define PB15 GPIO(GPIO_PORTB, 15) // DANIEL MO
	// Initial setup of SPI peripheral. We will need to tristate MOSI during Interface Mode
	ioport_set_pin_mode(SPI_MISO_PIN,SPI_MISO_MODE);
	ioport_disable_pin(SPI_MISO_PIN);
	ioport_set_pin_mode(SPI_MOSI_PIN,SPI_MOSI_MODE);
	ioport_disable_pin(SPI_MOSI_PIN);
	ioport_set_pin_mode(SPI_SPCK_PIN,SPI_SPCK_MODE);
	ioport_disable_pin(SPI_SPCK_PIN);
	ioport_set_pin_mode(SPI_NPCS_PIN,SPI_NPCS_MODE);
	ioport_disable_pin(SPI_NPCS_PIN);
	
	
// 	pmc_enable_periph_clk(SPI_ID);// turns on module/clock DANIEL Probably dont need

	SPI_MASTER_BASE->SPI_CR = SPI_CR_SPIDIS; //Disabled SPI
	SPI_MASTER_BASE->SPI_CR = SPI_CR_SWRST; //Resets SPI
	SPI_MASTER_BASE->SPI_CR = SPI_CR_LASTXFER; //De-asserts NPCS after every TD transfer.
	SPI_MASTER_BASE->SPI_MR |= SPI_MR_MSTR; //Sets to master mode
	SPI_MASTER_BASE->SPI_MR |= SPI_MR_MODFDIS; //Disables fault detection
	
	// Sets Peripheral Chip Select (chip select selects the integrated device circuit)
	// The Naneye doesn't actually use chip select but might be still nice to have for debugging on a scope
	SPI_MASTER_BASE->SPI_MR &= (~SPI_MR_PCS_Msk); //Empties out the PCS bits
	SPI_MASTER_BASE->SPI_MR |= SPI_MR_PCS(SPI_CHIP_PCS); //Sets the PCS bits
	
	// Sets Polarity for chip select
	// 0 means the clock is normally resting at 0
	SPI_MASTER_BASE->SPI_CSR[SPI_CHIP_SEL] &= (~SPI_CSR_CPOL); //0
	
	// Peripheral chip select line rises after each transfer for a minimum of DLYBCS
	//SPI_MASTER_BASE->SPI_CSR[SPI_CHIP_SEL] |= SPI_CSR_CSNAAT;
	
	//Bits Per Transfer
	SPI_MASTER_BASE->SPI_CSR[SPI_CHIP_SEL] &= (~SPI_CSR_BITS_Msk);
	SPI_MASTER_BASE->SPI_CSR[SPI_CHIP_SEL] |= SPI_CSR_BITS_8_BIT;

	//Set BAUD rate div CHECK ACTUAL SCLK OUTPUT!!!
	SPI_MASTER_BASE->SPI_CSR[SPI_CHIP_SEL] &= (~SPI_CSR_SCBR_Msk);
	SPI_MASTER_BASE->SPI_CSR[SPI_CHIP_SEL] |= SPI_CSR_SCBR(sysclk_get_peripheral_hz()/ SPI_CLK_RATE);

	//Set Delays
	SPI_MASTER_BASE->SPI_CSR[SPI_CHIP_SEL] &= ~(SPI_CSR_DLYBS_Msk | SPI_CSR_DLYBCT_Msk);
	SPI_MASTER_BASE->SPI_CSR[SPI_CHIP_SEL] |= SPI_CSR_DLYBS(SPI_DLYBS) | SPI_CSR_DLYBCT(SPI_DLYBCT);
	
	//Sets Delay of NPCS is held high between transfers
	SPI_MASTER_BASE->SPI_MR &= (~SPI_MR_DLYBCS_Msk);
	SPI_MASTER_BASE->SPI_MR |= SPI_MR_DLYBCS(SPI_DLYBCS);
	
	
	SPI_MASTER_BASE->SPI_CR = SPI_CR_SPIEN; //Enable SPI!
}

void spi_config_readout_mode(void) {
	// Set MOSI as tristate and set phase
	// DANIEL, this should be changed to the SAMD framework
	SPI_MASTER_BASE->SPI_CR = SPI_CR_SPIDIS; //Disabled SPI
	
	ioport_enable_pin(SPI_MOSI_PIN); // This should give PIO control back of the pin
	ioport_set_pin_dir(SPI_MOSI_PIN, IOPORT_DIR_INPUT);
	
	
	// In readout mode the naneye transmits a new bit on reach rising redge
	SPI_MASTER_BASE->SPI_CSR[SPI_CHIP_SEL] &= (~SPI_CSR_NCPHA); //0
	
	SPI_MASTER_BASE->SPI_CR = SPI_CR_SPIEN; //Enable SPI!
}

void spi_xdmac_configure(Spi *const pspi)
{
	// Here we will configure all 6 DMA transfer types
	// We need to toggle on and off the tristate for MOSI so using linked lists won't be too useful

	pmc_enable_periph_clk(ID_XDMAC);  // DANIEL probably dont need this function
	
	// Set transfer size
	xdmac_cfg[INTERFACE_MODE_TX_POS].mbr_ubc = INTERFACE_MODE_SIZE;
	xdmac_cfg[INTERFACE_MODE_RX_POS].mbr_ubc = INTERFACE_MODE_SIZE;
	// set delay mode size
	xdmac_cfg[SYNC_AND_DELAY_MODE_TX_POS].mbr_ubc = SYNC_MODE_SIZE + DELAY_MODE_MIN_SIZE;
	xdmac_cfg[SYNC_AND_DELAY_MODE_RX_POS].mbr_ubc = SYNC_MODE_SIZE + DELAY_MODE_MIN_SIZE;
	// set readout mode size
	xdmac_cfg[READOUT_MODE_TX_POS].mbr_ubc = READOUT_MODE_SIZE;
	xdmac_cfg[READOUT_MODE_RX_POS].mbr_ubc = READOUT_MODE_SIZE;
	// set readout mode size
	xdmac_cfg[INITIAL_INTERFACE_MODE_TX_POS].mbr_ubc = INITIAL_INTERFACE_MODE_SIZE;
	xdmac_cfg[INITIAL_INTERFACE_MODE_RX_POS].mbr_ubc = INITIAL_INTERFACE_MODE_SIZE;
	
	
	// Set source (interface mode) address
	xdmac_cfg[INTERFACE_MODE_TX_POS].mbr_sa = (uint32_t)&spi_interface_mode_tx_buffer[0]; // memory to memory
	xdmac_cfg[INTERFACE_MODE_RX_POS].mbr_sa = (uint32_t)&pspi->SPI_RDR; // receive register of the naneye
	// set sync mode address
	xdmac_cfg[SYNC_AND_DELAY_MODE_TX_POS].mbr_sa = (uint32_t)&spi_dma_trash[0];
	xdmac_cfg[SYNC_AND_DELAY_MODE_RX_POS].mbr_sa = (uint32_t)&pspi->SPI_RDR;
	// set readout mode address
	xdmac_cfg[READOUT_MODE_TX_POS].mbr_sa = (uint32_t)&spi_dma_trash[0];
	xdmac_cfg[READOUT_MODE_RX_POS].mbr_sa = (uint32_t)&pspi->SPI_RDR; // naneye camera read in is set to spi_rdr (read data register for SPI)
	// set readout mode address
	xdmac_cfg[INITIAL_INTERFACE_MODE_TX_POS].mbr_sa = (uint32_t)&spi_interface_mode_tx_buffer[0];
	xdmac_cfg[INITIAL_INTERFACE_MODE_RX_POS].mbr_sa = (uint32_t)&pspi->SPI_RDR; // naneye camera read in is set to spi_rdr (read data register for SPI)
	
	// Set destination interface mode address
	xdmac_cfg[INTERFACE_MODE_TX_POS].mbr_da = (uint32_t)&(pspi->SPI_TDR);
	xdmac_cfg[INTERFACE_MODE_RX_POS].mbr_da = (uint32_t)&spi_dma_trash[1];
	// set sync and delay mode address
	xdmac_cfg[SYNC_AND_DELAY_MODE_TX_POS].mbr_da = (uint32_t)&(pspi->SPI_TDR);
	xdmac_cfg[SYNC_AND_DELAY_MODE_RX_POS].mbr_da = (uint32_t)&spi_dma_trash[1];
	// set readout mode address
	xdmac_cfg[READOUT_MODE_TX_POS].mbr_da = (uint32_t)&(pspi->SPI_TDR);
	xdmac_cfg[READOUT_MODE_RX_POS].mbr_da = (uint32_t)&spi_readout_mode_rx_buffer[spi_buffer_write_index][0]; // This will change to different buffer positions during frame acq
	// set initial interface mode address
	xdmac_cfg[INITIAL_INTERFACE_MODE_TX_POS].mbr_da = (uint32_t)&(pspi->SPI_TDR);
	xdmac_cfg[INITIAL_INTERFACE_MODE_RX_POS].mbr_da = (uint32_t)&spi_dma_trash[1]; // This will change to different buffer positions during frame acq
	
	// Set rest of DMA config values
	// NOTE: Potentially can increase DWIDTH, CHUCK size, and/or MBSIZE to improve performance but not sure
	uint32_t common_tx_cfg = XDMAC_CC_TYPE_PER_TRAN |
	XDMAC_CC_MBSIZE_SINGLE |
	XDMAC_CC_DSYNC_MEM2PER |
	XDMAC_CC_CSIZE_CHK_1 |
	XDMAC_CC_DWIDTH_BYTE |
	XDMAC_CC_SIF_AHB_IF0 |
	XDMAC_CC_DIF_AHB_IF1 |
	XDMAC_CC_DAM_FIXED_AM |
	XDMAC_CC_PERID(SPI0_XDMAC_TX_CH_NUM);
	
	uint32_t common_rx_cfg = XDMAC_CC_TYPE_PER_TRAN |
	XDMAC_CC_MBSIZE_SINGLE |
	XDMAC_CC_DSYNC_PER2MEM |
	XDMAC_CC_CSIZE_CHK_1 |
	XDMAC_CC_DWIDTH_BYTE|
	XDMAC_CC_SIF_AHB_IF1 |
	XDMAC_CC_DIF_AHB_IF0 |
	XDMAC_CC_SAM_FIXED_AM |
	XDMAC_CC_PERID(SPI0_XDMAC_RX_CH_NUM);
	//
	xdmac_cfg[INTERFACE_MODE_TX_POS].mbr_cfg = common_tx_cfg | XDMAC_CC_SAM_INCREMENTED_AM;
	xdmac_cfg[INTERFACE_MODE_RX_POS].mbr_cfg = common_rx_cfg | XDMAC_CC_DAM_FIXED_AM;
	
	xdmac_cfg[SYNC_AND_DELAY_MODE_TX_POS].mbr_cfg = common_tx_cfg | XDMAC_CC_SAM_FIXED_AM;
	xdmac_cfg[SYNC_AND_DELAY_MODE_RX_POS].mbr_cfg = common_rx_cfg | XDMAC_CC_DAM_FIXED_AM;
	
	xdmac_cfg[READOUT_MODE_TX_POS].mbr_cfg = common_tx_cfg | XDMAC_CC_SAM_FIXED_AM;
	xdmac_cfg[READOUT_MODE_RX_POS].mbr_cfg = common_rx_cfg | XDMAC_CC_DAM_INCREMENTED_AM;
	
	xdmac_cfg[INITIAL_INTERFACE_MODE_TX_POS].mbr_cfg = common_tx_cfg | XDMAC_CC_SAM_FIXED_AM;
	xdmac_cfg[INITIAL_INTERFACE_MODE_RX_POS].mbr_cfg = common_rx_cfg | XDMAC_CC_DAM_INCREMENTED_AM;


	// Setting some final dma config stuff
	for (uint8_t i = 0; i < 6; i++) {
		xdmac_cfg[i].mbr_bc = 0;
		xdmac_cfg[i].mbr_ds =  0;
		xdmac_cfg[i].mbr_sus = 0;
		xdmac_cfg[i].mbr_dus = 0;
	}

	// Set up first DMA tx and rx configuration
	// Can remove this
	xdmac_configure_transfer(XDMAC, XDMAC_TX_CH, &xdmac_cfg[INTERFACE_MODE_TX_POS]);
	xdmac_configure_transfer(XDMAC, XDMAC_RX_CH, &xdmac_cfg[INTERFACE_MODE_RX_POS]);

	

}

// NOTE: No idea of switching the mode of the MOSI pin is allowed
void spi_config_interface_mode(void) {
	// Set MOSI as output and set phase
	
	SPI_MASTER_BASE->SPI_CR = SPI_CR_SPIDIS; //Disabled SPI
	// sets the pin to SPI MISO/MOSI pinsO
	ioport_set_pin_mode(SPI_MOSI_PIN,SPI_MOSI_MODE);
	ioport_disable_pin(SPI_MOSI_PIN);
	
	// In interface mode the naneye samples the data pin on the rising edge
	SPI_MASTER_BASE->SPI_CSR[SPI_CHIP_SEL] |= SPI_CSR_NCPHA; //1
	
	SPI_MASTER_BASE->SPI_CR = SPI_CR_SPIEN; //Enable SPI!
}


// NOTE: No idea of switching the mode of the MOSI pin is allowed
void spi_config_initial_interface_mode(void) {
	// Set MOSI as output and set phase
	SPI_MASTER_BASE->SPI_CR = SPI_CR_SPIDIS; //Disabled SPI
	// sets the pin to SPI MISO/MOSI pinsO
	ioport_set_pin_mode(SPI_MOSI_PIN,SPI_MOSI_MODE);
	ioport_disable_pin(SPI_MOSI_PIN);
	
	// In interface mode the naneye samples the data pin on the rising edge
	SPI_MASTER_BASE->SPI_CSR[SPI_CHIP_SEL] |= SPI_CSR_NCPHA; //1

	SPI_MASTER_BASE->SPI_CR = SPI_CR_SPIEN; //Enable SPI!
	
	SPI_MASTER_BASE->SPI_TDR= 0b00; // HS added sends blank signal to initialize, per NE sequence of operation
	// 	SPI_MASTER_BASE->SPI_TDR= 0b00; // HS added sends blank signal to initialize, per NE sequence of operation

}
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
// int main (void)
int NanEyeRUN (void)
{

	uint32_t lastToggleTime;
	
	WDT->WDT_MR = WDT_MR_WDDIS; //Disables Watch dog timer, independent timer
	
	// Init interrupt handling
	irq_initialize_vectors();
	cpu_irq_enable();
	
	// Init system clock and board stuff
	sysclk_init(); // HS starts the clock
	board_init(); // NEEDED TO DISABLE CASHE!!!!!!!
	
	
	// Init SPI master
	spi_init(); // initializes SPI transfer
	
	// Init DMA handling SPI data reads for 3 tx and 3 rx DMA types
	// link one byte without stopping between bytes over spi
	spi_xdmac_configure(SPI_MASTER_BASE);
	
	// Setup interrupt priority
	// NVIC: Nested vector interrupt controller
	NVIC_ClearPendingIRQ(XDMAC_IRQn); //Clear a device specific interrupt from pending.
	NVIC_DisableIRQ(XDMAC_IRQn); // Disable a device specific interrupt.
	NVIC_SetPriority( XDMAC_IRQn ,1); // Set priority grouping -
	NVIC_EnableIRQ(XDMAC_IRQn); // Enable a device specific interrupt
	
	// Systick Init for handling keeping track of time
	//systick_init(); // DANIEL PROBABLY DONT NEED THIS
	
	// USART enable UART for serial comm
	//pmc_enable_periph_clk(ID_USART1); // Enable the specified peripheral clock.

	/* // DANIEL WE DONT NEED THIS
	usart_serial_options_t usart_options = {
		.baudrate = CONF_UART_BAUDRATE,
		.charlength = US_MR_CHRL_8_BIT,
		.paritytype = US_MR_PAR_NO,
		.stopbits = US_MR_NBSTOP_1_BIT
	};
	usart_serial_init(CONF_UART, &usart_options);
	*/
	// Fill interface buffer with all 1's
	interface_buffer_init(); // Just sets all values to 0xFF here
	
	// sets state of the Naneye, this is a bitshift operation
	state = STATE_IDLE;
	
	// Used for tx and rx in DMA when we don't need to save the data
	spi_dma_trash[0] = 0x00;
	spi_dma_trash[1] = 0x00;
	lastToggleTime = ms_ticks;
	// Pause for a few 100ms to make sure the naneye is ready
	while (ms_ticks < (lastToggleTime + 1000)) {}
	
	// Let's start naneye communication. To do this we will finish setting up the interface mode stuff and then turn on the DMAs
	naneye_new_reg_val_received = 1;
	
	// Initial initialization sequence
	//spi_enable_xdmac(); // HS added, but this is a roundabout way of doing this (we should be using xdmac configure transfer)
	//spi_disable_xdmac();// HS added, but this is a roundabout way of doing this (we should be using xdmac configure transfer)

	//xdmac_configure_transfer(XDMAC, XDMAC_TX_CH, &xdmac_cfg[0]);// HS gives the address for the 1st array in xdmac_cfg array
	//xdmac_configure_transfer(XDMAC, XDMAC_RX_CH, &xdmac_cfg[0]);// HS gives the address for the 2nd array in xdmac_cfg array
	
	// sets naneye register
	// the 10th bit is the 11th value when read from the right to left
	// |= sets particular value to 1
	// &= with a ~ means and not, sets value to 0
	// ~ also inverts the orientation means and not, sets value to 0
	
	naneyec_reg_val[0] = NANEYE_REG0_DEFAULT_VALUE | 0b1100; // Sets offset ramp to recommended 2.2V value
	naneyec_reg_val[0] = naneyec_reg_val[0] | 0b11; // HS turned off Sets output current to max (might only affect LVDS mode)
	

	naneyec_reg_val[1] = NANEYE_REG1_DEFAULT_VALUE;
	naneyec_reg_val[1] |= (1<<10); // Increase 2x bias current, reduces settling time for high speed apps (not sure what this does)
	naneyec_reg_val[1] &= ~(1<<9); // Sets CDS gain to recommended value of 1.3 (turns a 1--> 0, which sets CDS gain to 1.3)
	naneyec_reg_val[1] &= ~(1<<8); // Sets mode to SEIM
	naneyec_reg_val[1] = (naneyec_reg_val[1] & (0b1111111111001111)) | (0b10 << 4); // Sets vref to recommended value of 2.1V
	naneyec_reg_val[1] = (naneyec_reg_val[1] & (0b1111111111110011)) | (0b01 << 2); // Sets CVC current to recommended value
	naneyec_reg_val[1] &= ~(1<<1); // Turns off idle mode
	spi_config_initial_interface_mode(); // HS added function initializes IIM sequence
	// SPI_MASTER_BASE->SPI_TDR= 0b00; // HS Added sends signal to the SPI_TDR transfer register to send out

	interface_buffer_reg_set(naneyec_reg_val[0],naneyec_reg_val[1]);
	//// ADD PRESYNC HERE
	spi_config_interface_mode(); // This enables the MOSI peripheral pin and sets the correct clock phase
	// Set the correct DMA transfer config (forcing MOSI pin to be internally connected in readout mode)
	// 2 DMA running in parallel
// 	xdmac_configure_transfer(XDMAC, XDMAC_TX_CH, &xdmac_cfg[INTERFACE_MODE_TX_POS]);//  gives the address for the 1st array in xdmac_cfg array
// 	xdmac_configure_transfer(XDMAC, XDMAC_RX_CH, &xdmac_cfg[INTERFACE_MODE_RX_POS]);//  gives the address for the 2nd array in xdmac_cfg array
	delay_ms(1000);
	// Later will need to add a 10us delay after sending out the configuration
	spi_enable_xdmac(); // this is where the pulses begin to get sent out
	state = STATE_INTERFACE;
	
	uint8_t naneye_data[2];
	uint8_t debug_data[120];
	uint32_t start_pos = 0;
	
	uint32_t tempVal;
	uint8_t frame_idx_to_send = 0;
	// this portion of the code is inefficient because each loop checks the register bit values to see if there is data, and then runs the dmac controller.
	// runs forever
	while (1) {
		// Serial communication over USB
		uart_handle_input(); // This checks if there is uart char received and then does stuff with it
		// if there is a frame requested,
		if (frame_requested) {
			// send all pixels over UART
			frame_idx_to_send = (spi_buffer_write_index + 1) % 2; // grabs the frame not being written to currently
			// sends 12 bit pixel 2x value over 8 bits after 3x
			for (uint32_t i = 0; i < READOUT_MODE_SIZE; i += 3) {
				// loop that writes out data from frame buffer if frame is requested by user
				tempVal = spi_readout_mode_rx_buffer[frame_idx_to_send][start_pos + i] << 16 | spi_readout_mode_rx_buffer[frame_idx_to_send][start_pos + (i + 1)] << 8 | spi_readout_mode_rx_buffer[frame_idx_to_send][start_pos + (i + 2)];
				naneye_data[0] = (tempVal >> 15) & 0xFF;
				naneye_data[1] = (tempVal >> 3) & 0xFF;
				// does this squelch out a data vector of the naneye?
				usart_serial_write_packet(CONF_UART,naneye_data,2);
				
			}
			frame_requested = false;
			
		}
		// LED toggling for debugging
		if (ms_ticks > (lastToggleTime + 500)) {
			if (debug_mode) {
				// output debug info to console
				for (uint8_t i = 0; i < 120; i++)
				debug_data[i] = spi_readout_mode_rx_buffer[frame_idx_to_send][i];
				usart_serial_write_packet(CONF_UART,debug_data,120);
			}
			
			lastToggleTime = ms_ticks;;
			ioport_toggle_pin_level(LED0_GPIO);
		}
	}

	/* Insert application code here, after the board has been initialized. */
}
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

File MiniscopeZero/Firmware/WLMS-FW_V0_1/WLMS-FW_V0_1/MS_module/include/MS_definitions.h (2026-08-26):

/**
@file
@brief Internal definitions and parameters. All application specific functions should be declared here.
@author Takuya
*/

#ifndef MS_DEFINITIONS_H_
#define MS_DEFINITIONS_H_

#include <atmel_start.h>
#include <utils.h>

#include "MS_config.h"

// Peripheral address
#define EWL_I2C_ADDR					0x23  //7 bit address!

// ------ OTHER STUFF ------------------------
#define MS_SUCCESS						1
#define MS_ERROR						0
// -------------------------------------------

// ---------- Device State Definitions -------
#define DEVICE_STATE_IDLE				1<<1
#define DEVICE_STATE_START_RECORDING	1<<2
#define DEVICE_STATE_RECORDING			1<<3
#define DEVICE_STATE_STOP_RECORDING		1<<4
#define DEVICE_STATE_CHARGING			1<<5
#define DEVICE_STATE_CONFIG_LOADED		1<<6
#define DEVICE_STATE_ERROR				1<<7
#define DEVICE_STATE_LOW_VOLTAGE		1<<8
#define DEVICE_STATE_START_RECORDING_WAITING	1<<9
#define DEVICE_STATE_SDCARD_WRITE_ERROR			1<<10
#define DEVICE_STATE_SDCARD_INIT_WRITE_ERROR	1<<11
// -------------------------------------------

// ----------- Buffer Definitions ------------
#define PCC_BLOCK_SIZE_IN_WORDS		128
#ifdef SDO_32BIT_ENABLE
#define SDO_BLOCK_SIZE_IN_WORDS		128 // (512 bytes) / (4 byte word size)
#endif
#ifdef SDO_8BIT_ENABLE
#define SDO_BLOCK_SIZE_IN_WORDS		512 // (512 bytes) / (1 byte word size)
#endif

// Buffer Header position definitions
#define BUFFER_HEADER_LENGTH					12
#define BUFFER_HEADER_HEADER_LENGTH_POS			0
#define BUFFER_HEADER_LINKED_LIST_POS			1
#define BUFFER_HEADER_FRAME_NUM_POS				2
#define BUFFER_HEADER_BUFFER_COUNT_POS			3
#define BUFFER_HEADER_FRAME_BUFFER_COUNT_POS	4
#define BUFFER_HEADER_WRITE_BUFFER_COUNT_POS	5
#define BUFFER_HEADER_DROPPED_BUFFER_COUNT_POS	6
#define BUFFER_HEADER_TIMESTAMP_POS				7
#define BUFFER_HEADER_DATA_LENGTH_POS			8
#define BUFFER_HEADER_WRITE_TIMESTAMP_POS		9
#define BUFFER_HEADER_BATTERY_VOLTAGE_POS		10
#define BUFFER_HEADER_WPT_VOLTAGE_POS			11

// -------------------------------------------

// ------------ Config Block Definitions -----
#define CONFIG_BLOCK_WIDTH_POS					0
#define CONFIG_BLOCK_HEIGHT_POS					1
#define CONFIG_BLOCK_FRAME_RATE_POS				2
#define CONFIG_BLOCK_BUFFER_SIZE_POS			3
#define CONFIG_BLOCK_NUM_BUFFERS_RECORDED_POS	4
#define CONFIG_BLOCK_NUM_BUFFERS_DROPPED_POS	5
// -------------------------------------------

// ------------ ADC channel Definitions -----
#define ADC_CHANNEL_BATTERY						0
#define ADC_CHANNEL_POWERBUS					2
// -------------------------------------------

// -------------------------------------------
// -------------- SD Definitions -------------
#define STARTING_BLOCK				1024
// This is only used in non-DMA operation
#define NB_BUFFER_WRITES_PER_CHUNK	20 // Can be edited by user to optimize speed

//#define HEADER_BLOCK				STARTING_BLOCK - 2  //1022
#define HEADER_BLOCK				1022  //1022
#define CONFIG_BLOCK				STARTING_BLOCK - 1  //1023

#define SD_BLOCK_SIZE					512 //Number of bytes in a single block (sector)

#define SD_DESCRIPTOR_ATT_VALID			1
#define SD_DESCRIPTOR_ATT_END			1<<1
#define SD_DESCRIPTOR_ATT_Int			1<<2
#define SD_DESCRIPTOR_LENGTH(val)		(val<<16)
#define SD_DESCRIPTOR_ATT_TRANSFER		(1<<5)
#define SD_DESCRIPTOR_ATT_LINK			(3<<4)

// Write Key Protection Values
#define WRITE_KEY0					0x0D7CBA17
#define WRITE_KEY1					0x0D7CBA17
#define WRITE_KEY2					0x0D7CBA17
#define WRITE_KEY3					0x0D7CBA17

// SD Header Definitions
#define HEADER_GAIN_POS				4
#define HEADER_LED_POS				5
#define HEADER_EWL_POS				6
#define HEADER_RECORD_LENGTH_POS	7
#define HEADER_FRAME_RATE_POS		8
#define HEADER_DELAY_START_POS		9
#define HEADER_BATT_CUTOFF_POS		10

#define HEADER_EWL_SCAN_ENABLE_POS 	11
#define HEADER_EWL_START_POS 		12
#define HEADER_EWL_STOP_POS 		13
#define HEADER_EWL_STEP_POS 		14
#define HEADER_EWL_STEP_TIME_POS 	15
// -------------------------------------------

// ADC Level Definition
#define ADC_BATTERY_LOW		186 // 4.0 V (x5 attenuation, 8-bit)
//#define ADC_BATTERY_LOW		177 // 3.8 V (x5 attenuation, 8-bit)
#define ADC_BATTERY_HIGH	191 // 4.1 V (x5 attenuation, 8-bit)
#define ADC_WPT_LOW			89 // 4.2 V (x11 attenuation, 8-bit)
#define ADC_WPT_HIGH		169 // 8 V (x11 attenuation, 8-bit)
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

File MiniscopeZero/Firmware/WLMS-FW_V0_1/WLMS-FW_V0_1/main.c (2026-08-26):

#include <atmel_start.h>
#include "MS_config.h"
#include "MS_definitions.h"

int main(void)
{
	#ifdef PYTHON480_ENABLE
	getBuffersPerFrame();
	#endif
	
	/* Initializes MCU, drivers and middleware */
	atmel_start_init();

	//Note sure if this is needed. Takuya
	__disable_irq();

	DataBufferInit(); // For testing buffer to SERCOM DMA

	peripheralInit();

	#ifdef DMA_TO_SD_ENABLE
	debugHeaderProp();
	#endif
	
	dmaEnable();
	
	//Note sure if this is needed. Takuya
	__enable_irq();

	#ifdef AUTOSTART_ENABLE
	delay_ms(1000);
	deviceState = DEVICE_STATE_START_RECORDING;
	#endif
		
	while (1) { // mostly recording_cb and framevalid_cb runs here
		#if defined(PYTHON480_ENABLE)
		if (deviceState & DEVICE_STATE_START_RECORDING){
			startRecording();
		}
		
		if (deviceState & DEVICE_STATE_RECORDING) {
			#ifdef DMA_TO_SD_ENABLE
			sdmmc_dma_transfer_control();
			#endif
		}
		// Module for stopping recording. Only needed for SD card
		if (deviceState & DEVICE_STATE_STOP_RECORDING) {
			stopRecording();
		}
		#endif //#if defined(PYTHON480_ENABLE)
		
		//Only for testing DMA to serial data out
		#ifndef PYTHON480_ENABLE
		//sdo_dma_transfer_control(false);
		#endif
	}
}

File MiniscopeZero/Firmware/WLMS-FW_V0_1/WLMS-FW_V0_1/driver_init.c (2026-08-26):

/*
 * Code generated from Atmel Start.
 *
 * This file will be overwritten when reconfiguring your Atmel Start project.
 * Please copy examples or other code you want to keep to a separate file
 * to avoid losing it when reconfiguring.
 */

#include "driver_init.h"
#include <peripheral_clk_config.h>
#include <utils.h>
#include <hal_init.h>

#include <hpl_adc_base.h>
#include <hpl_adc_base.h>

/*! The buffer size for USART */
#define USART_0_BUFFER_SIZE 16

struct usart_async_descriptor USART_0;
struct spi_m_sync_descriptor  SPI_0;
struct timer_descriptor       TIMER_0;

static uint8_t USART_0_buffer[USART_0_BUFFER_SIZE];

struct adc_sync_descriptor ADC_0;

struct adc_sync_descriptor ADC_1;

struct camera_async_descriptor CAMERA_0;

struct pwm_descriptor PWM_0;

void ADC_0_PORT_init(void)
{

	// Disable digital pin circuitry
	gpio_set_pin_direction(BATT_VOLT, GPIO_DIRECTION_OFF);

	gpio_set_pin_function(BATT_VOLT, PINMUX_PA02B_ADC0_AIN0);
}

void ADC_0_CLOCK_init(void)
{
	hri_mclk_set_APBDMASK_ADC0_bit(MCLK);
	hri_gclk_write_PCHCTRL_reg(GCLK, ADC0_GCLK_ID, CONF_GCLK_ADC0_SRC | (1 << GCLK_PCHCTRL_CHEN_Pos));
}

void ADC_0_init(void)
{
	ADC_0_CLOCK_init();
	ADC_0_PORT_init();
	adc_sync_init(&ADC_0, ADC0, (void *)NULL);
}

void ADC_1_PORT_init(void)
{

	// Disable digital pin circuitry
	gpio_set_pin_direction(WPT_VOLT, GPIO_DIRECTION_OFF);

	gpio_set_pin_function(WPT_VOLT, PINMUX_PB08B_ADC1_AIN0);
}

void ADC_1_CLOCK_init(void)
{
	hri_mclk_set_APBDMASK_ADC1_bit(MCLK);
	hri_gclk_write_PCHCTRL_reg(GCLK, ADC1_GCLK_ID, CONF_GCLK_ADC1_SRC | (1 << GCLK_PCHCTRL_CHEN_Pos));
}

void ADC_1_init(void)
{
	ADC_1_CLOCK_init();
	ADC_1_PORT_init();
	adc_sync_init(&ADC_1, ADC1, (void *)NULL);
}

void EXTERNAL_IRQ_0_init(void)
{
	hri_gclk_write_PCHCTRL_reg(GCLK, EIC_GCLK_ID, CONF_GCLK_EIC_SRC | (1 << GCLK_PCHCTRL_CHEN_Pos));
	hri_mclk_set_APBAMASK_EIC_bit(MCLK);

	// Set pin direction to input
	gpio_set_pin_direction(nCHRG, GPIO_DIRECTION_IN);

	gpio_set_pin_pull_mode(nCHRG,
	                       // <y> Pull configuration
	                       // <id> pad_pull_config
	                       // <GPIO_PULL_OFF"> Off
	                       // <GPIO_PULL_UP"> Pull-up
	                       // <GPIO_PULL_DOWN"> Pull-down
	                       GPIO_PULL_OFF);

	gpio_set_pin_function(nCHRG, PINMUX_PB23A_EIC_EXTINT7);

	// Set pin direction to input
	gpio_set_pin_direction(PUSH_BUT_MCU, GPIO_DIRECTION_IN);

	gpio_set_pin_pull_mode(PUSH_BUT_MCU,
	                       // <y> Pull configuration
	                       // <id> pad_pull_config
	                       // <GPIO_PULL_OFF"> Off
	                       // <GPIO_PULL_UP"> Pull-up
	                       // <GPIO_PULL_DOWN"> Pull-down
	                       GPIO_PULL_OFF);

	gpio_set_pin_function(PUSH_BUT_MCU, PINMUX_PA25A_EIC_EXTINT9);

	// Set pin direction to input
	gpio_set_pin_direction(FrameValid, GPIO_DIRECTION_IN);

	gpio_set_pin_pull_mode(FrameValid,
	                       // <y> Pull configuration
	                       // <id> pad_pull_config
	                       // <GPIO_PULL_OFF"> Off
	                       // <GPIO_PULL_UP"> Pull-up
	                       // <GPIO_PULL_DOWN"> Pull-down
	                       GPIO_PULL_OFF);

	gpio_set_pin_function(FrameValid, PINMUX_PB14A_EIC_EXTINT14);

	ext_irq_init();
}

void CAMERA_0_PORT_init(void)
{

	gpio_set_pin_function(PCC_CLK, PINMUX_PA14K_PCC_CLK);

	gpio_set_pin_function(PCC_D0, PINMUX_PA16K_PCC_DATA0);

	gpio_set_pin_function(PCC_D1, PINMUX_PA17K_PCC_DATA1);

	gpio_set_pin_function(PCC_D2, PINMUX_PA18K_PCC_DATA2);

	gpio_set_pin_function(PCC_D3, PINMUX_PA19K_PCC_DATA3);

	gpio_set_pin_function(PCC_D4, PINMUX_PA20K_PCC_DATA4);

	gpio_set_pin_function(PCC_D5, PINMUX_PA21K_PCC_DATA5);

	gpio_set_pin_function(PCC_D6, PINMUX_PA22K_PCC_DATA6);

	gpio_set_pin_function(PCC_D7, PINMUX_PA23K_PCC_DATA7);

	gpio_set_pin_function(PCC_FV, PINMUX_PA12K_PCC_DEN1);

	gpio_set_pin_function(PCC_HV, PINMUX_PA13K_PCC_DEN2);
}

void CAMERA_0_CLOCK_init(void)
{
	hri_mclk_set_APBDMASK_PCC_bit(MCLK);
}

void CAMERA_0_init(void)
{
	CAMERA_0_CLOCK_init();
	camera_async_init(&CAMERA_0, PCC);
	CAMERA_0_PORT_init();
}

/**
 * \brief USART Clock initialization function
 *
 * Enables register interface and peripheral clock
 */
void USART_0_CLOCK_init()
{

	hri_gclk_write_PCHCTRL_reg(GCLK, SERCOM1_GCLK_ID_CORE, CONF_GCLK_SERCOM1_CORE_SRC | (1 << GCLK_PCHCTRL_CHEN_Pos));
	hri_gclk_write_PCHCTRL_reg(GCLK, SERCOM1_GCLK_ID_SLOW, CONF_GCLK_SERCOM1_SLOW_SRC | (1 << GCLK_PCHCTRL_CHEN_Pos));

	hri_mclk_set_APBAMASK_SERCOM1_bit(MCLK);
}

/**
 * \brief USART pinmux initialization function
 *
 * Set each required pin to USART functionality
 */
void USART_0_PORT_init()
{

	gpio_set_pin_function(PA00, PINMUX_PA00D_SERCOM1_PAD0);

	gpio_set_pin_function(IR_REC, PINMUX_PB22C_SERCOM1_PAD2);
}

/**
 * \brief USART initialization function
 *
 * Enables USART peripheral, clocks and initializes USART driver
 */
void USART_0_init(void)
{
	USART_0_CLOCK_init();
	usart_async_init(&USART_0, SERCOM1, USART_0_buffer, USART_0_BUFFER_SIZE, (void *)NULL);
	USART_0_PORT_init();
}
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

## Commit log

2026-05-08 add kicad gitignore
2026-05-08 Add Miniscope Zero motherboard/daugtherboard/RX-coil PCBs
    [475710001.stp, 5055501620.stp, ERJ-1GNF4023C.stp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]
2026-08-11 Add QSCR related mechanical design and PCB
    [arena_QSCR.f3z, c_mount.kicad_pcb, c_mount.kicad_sch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]
2026-08-11 Removed unused PCB files
    [rect_20_22.kicad_pcb, rect_20_22.kicad_sch, rect_20_22.step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]
2026-08-11 Optical DAQ downlink PCB
    [timer_usb_board_v0_2.kicad_pcb, timer_usb_board_v0_2.kicad_sch]
2026-08-11 Optical DAQ Digitizer and VGA
    [+3V3_LDO.kicad_sch, +3V3_LDO_HP.kicad_sch, PCBWay_bom.csv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]
2026-08-11 Opal Kelly breakout board
    [optical_rx_brk7010_v0_1.kicad_pcb, optical_rx_brk7010_v0_1.kicad_sch]
2026-08-11 Optical DAQ aluminum CNC box
    [Inlet.step, box.step, inlet.stl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]
2026-08-18 Fix breakout board name
    [optical_rx_brk7310_v0_1.kicad_pcb, optical_rx_brk7310_v0_1.kicad_sch]
2026-08-18 additional FPGA board name fixes
    [optical_rx_brk7310_v0_1.kicad_pcb, optical_rx_brk7310_v0_1.kicad_sch]
2026-08-18 Add Optics folder with BOM, mechanical drawing, and Zemax design files
    [optics_bom.csv]
2026-08-18 Add optical housing CAD: STEP, Fusion archive, and per-body STLs
    [Wireless_Miniscope_v_0_2_10.f3d, Wireless_Miniscope_v_0_2_10.step, base_unit.stl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]
2026-08-18 Add baseplate and dust cap CAD with manufacturing specifications
    [baseplate.step, baseplate.stl, baseplate_and_dustcap.f3z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]
2026-08-18 Add optics assembly guide and baseplate hardware list
    [baseplate_components.csv]
2026-08-18 Move optics assembly guide into guides/ and expand README tree
2026-08-18 Fix thread_location.png path in Optics README
2026-09-10 Change ignores for storing production artifacts.
    [PCBWay_bom.csv, PCBWay_positions.csv, bom.csv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]
2026-09-10 Scrub local user paths from PCB settings and lib tables
    [WLMS-v0_2_1-motherboard.kicad_pcb]

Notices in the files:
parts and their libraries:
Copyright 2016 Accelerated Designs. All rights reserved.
